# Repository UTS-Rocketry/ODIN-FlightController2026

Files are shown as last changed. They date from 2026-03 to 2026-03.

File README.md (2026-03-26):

# ODIN - UTS Rocketry – Flight Controller 2026

b32aecdc31f343ea89f31d750d7f50b3_T

## Version 1.0
Primary avionics flight controller for the 2026 AURC rocket.

This board manages flight state detection, sensor fusion, telemetry transmission, and onboard data logging using a 3.3V STM32-based embedded system.

---

## System Overview

### Microcontroller
- STM32 (F4 Series)
- 3.3V logic domain
- SWD debugging (ST-Link)
- Optional USB device (CDC / DFU)
- DMA-enabled peripherals
- Hardware timers for deterministic event timing

---

## Sensors

### Barometer (I2C)
- High-resolution pressure sensor
- Used for altitude estimation
- Data-ready interrupt supported (optional)
- VDD and VDDIO tied to 3.3V
- Local decoupling per datasheet

### IMU (Accelerometer + Gyroscope)
- Used for:
  - Boost detection
  - Apogee validation
  - Orientation monitoring
- Connected via SPI or I2C
- Interrupt-capable EXTI lines available

### GPS (UART)
- Real-time position tracking
- Logged to SD card
- Transmitted via LoRa telemetry
- Used for post-flight recovery

---

## Telemetry – SX1262 (SPI)

- LoRa-based long-range telemetry
- Configurable TX power & spreading factor
- SPI with DMA support
- Downlinked data:
  - Altitude
  - Velocity estimate
  - Flight state
  - GPS coordinates
  - Battery voltage

---

## Data Logging – microSD (SPI Mode)

- SPI selected over SDIO for routing simplicity and robustness
- 22Ω series resistor on SCK
- 10k pull-up on CS (DAT3)
- 0.1µF + 10µF local decoupling
- ESD protection on the connector

### Logged Parameters
- Timestamp
- Raw pressure
- Calculated altitude
- IMU acceleration & gyro
- GPS coordinates
- Flight state transitions
- Battery voltage
- Event flags

---

## Power Architecture

- Main system input rail
- 3.3V regulated logic rail
- ADC-based battery voltage monitoring (resistor divider)
- Local decoupling at each IC
- Bulk capacitance near SD and LoRa module

### Design Considerations
- All digital logic operates at 3.3V
- Short SPI traces with source termination
- Separation from switching regulator noise
- Solid ground reference plane

---

##  Programming & Debugging

### SWD (Primary Interface)
- SWDIO
- SWCLK
- GND
- 3.3V reference
- NRST (optional)

Used for:
- Firmware flashing
- Breakpoint debugging
- Register inspection

### USB (Optional)
- CDC virtual COM port for debug output
- Optional DFU firmware update support

---

### Core Features
- Sensor initialisation & health checks
- DMA-based peripheral handling
- Deterministic flight-state transitions
- SD logging with fault handling
- Telemetry packet scheduling
- Brownout and fault detection

---

# Contributors
 - Ollie Charleton: Avionics Lead
 - Michael Basangan: Software Lead
 - Aditya Sriram : Advisor

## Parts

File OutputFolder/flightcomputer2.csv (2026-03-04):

Reference | Qty | Value | LCSC
BZ1 | 1 | Buzzer | C96093
C1,C2,C5,C6,C7,C10,C11,C12,C14,C17,C18,C20,C21,C22,C23,C24,C25,C26,C27 | 19 | 100nf | C49678
C3,C4 | 2 | 2.2u | C19110
C8 | 1 | 4.7u | C1779
C9,C13,C28 | 3 | 1u | C28323
C15,C16 | 2 | 18p | C113825
C19 | 1 | 10u | C2932476
CAN_IN1,CAN_OUT1 | 2 | CAN | C17644051
D1 | 1 | NeoPixel_THT | C2827321
D2,D3 | 2 | D_Schottky | C113936
D4 | 1 | SRV05-4.TCT | C13612
D6 | 1 | 1N5819WS | C191023
FB1 | 1 | FerriteBead | C85840
J1 | 1 | Microsemi_FlashPro-JTAG-10 | C585350
J2,J4 | 2 | Pyro | C17644051
J5,J6 | 2 | Conn_01x05_Pin | C157991
J7 | 1 | Conn_Coaxial_Small | C3172376
J8 | 1 | Micro_SD_Card | C164170
J9 | 1 | USB_C_Receptacle_USB2.0_16P | C165948
PowerLED1 | 1 | RLED | C965799
Q1,Q2 | 2 | IRLML2502TRPBF | C2589
Q3 | 1 | BC817 | C39828
R1,R5,R10,R15,R17,R18,R20 | 7 | 10k | C84376
R2 | 1 | 100k | C96346
R3 | 1 | 1k | C95781
R4,R9 | 2 | 100R | C17408
R6,R11 | 2 | 75k | C17819
R7,R12 | 2 | 47k | C2933415
R8 | 1 | 120R | C269726
R13,R14 | 2 | 5.1k | C27834
R16 | 1 | 33R | C17557
R19 | 1 | 470r | C2907267
R21,R22 | 2 | 4.7k | C17673
SW1,SW2 | 2 | SAMZO G4R0015010 | C49393646
U1 | 1 | STM32F405RGT6 | C15742
U2 | 1 | SN65HVD230 | C1543812
U3 | 1 | PowerIn | C17644051
U4 | 1 | LDL1117-3.3 | C435835
U5 | 1 | RFM95W-915S2 | C2844473
U6 | 1 | MPL3115A2R1 | C54429
U7 | 1 | LSM6DS3TR-C | C967633
U8 | 1 | W25Q128JVP | C190862
U9 | 1 | H3LIS331DL | C2655074
Y1 | 1 | 8mhz | C19723344

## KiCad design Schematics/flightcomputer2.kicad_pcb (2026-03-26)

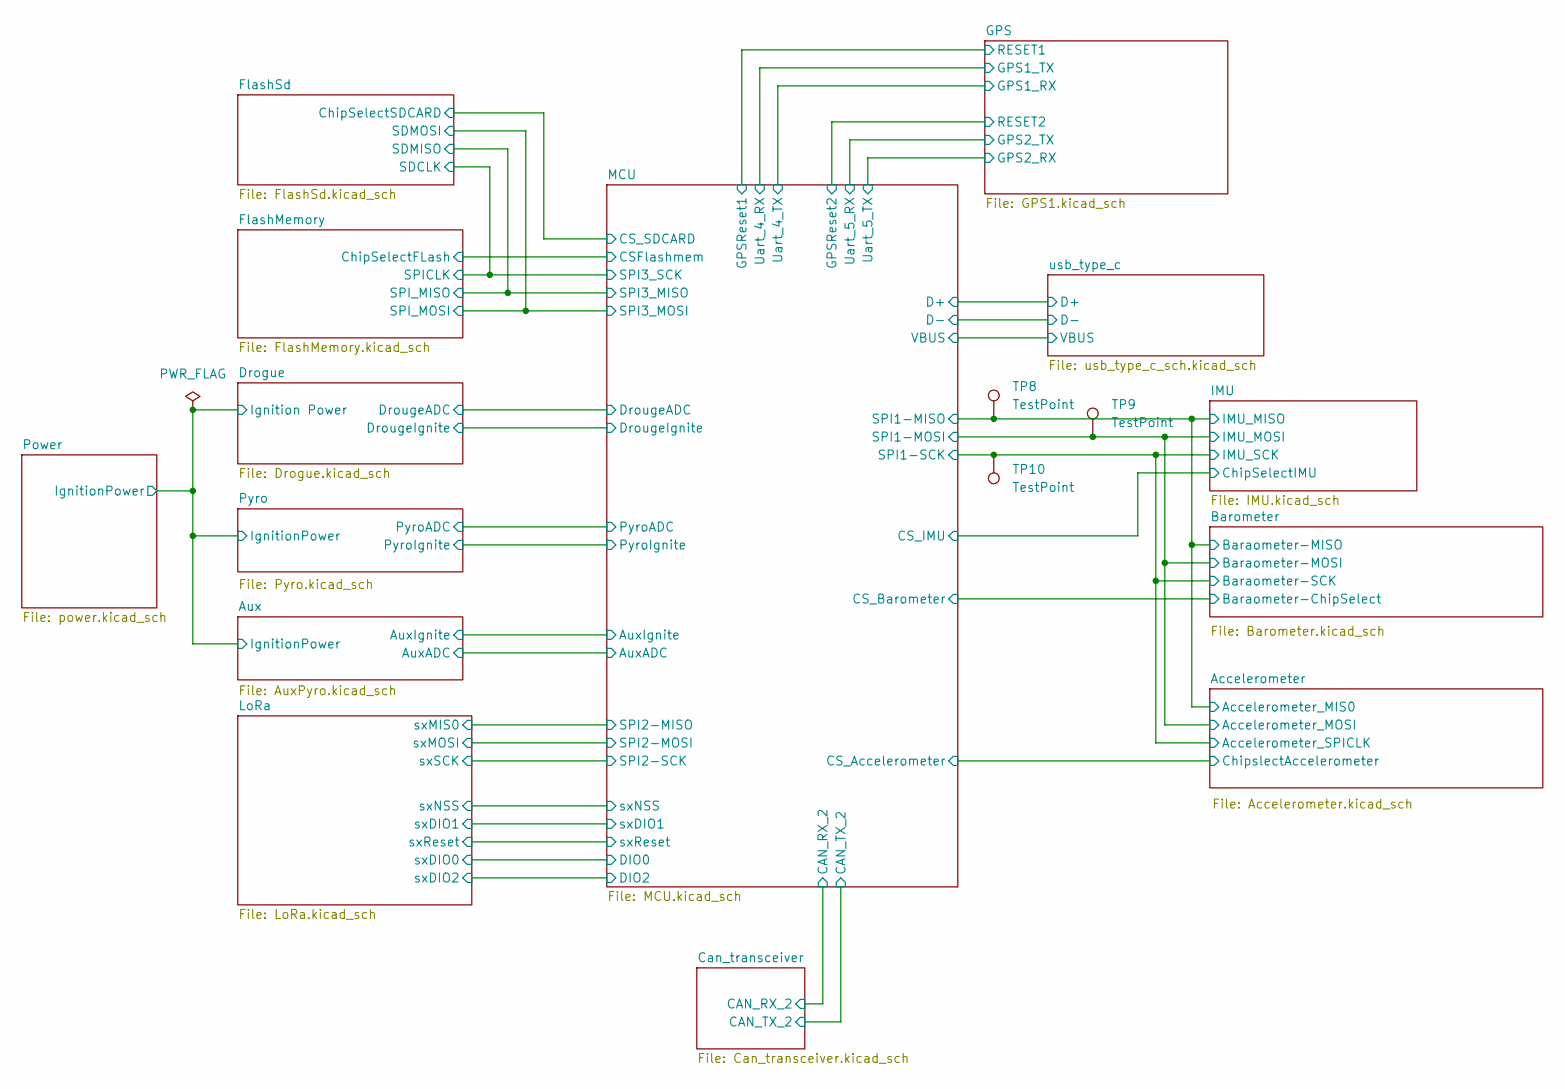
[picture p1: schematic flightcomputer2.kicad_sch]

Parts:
TP8, TP9, TP10: TestPoint; TestPoint_Pad_1.5x1.5mm

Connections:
/Accelerometer/Accelerometer_MIS0: TP8.1 (1_1); also elsewhere on the board
/Accelerometer/Accelerometer_MOSI: TP9.1 (1_1); also elsewhere on the board
/Accelerometer/Accelerometer_SPICLK: TP10.1 (1_1); also elsewhere on the board

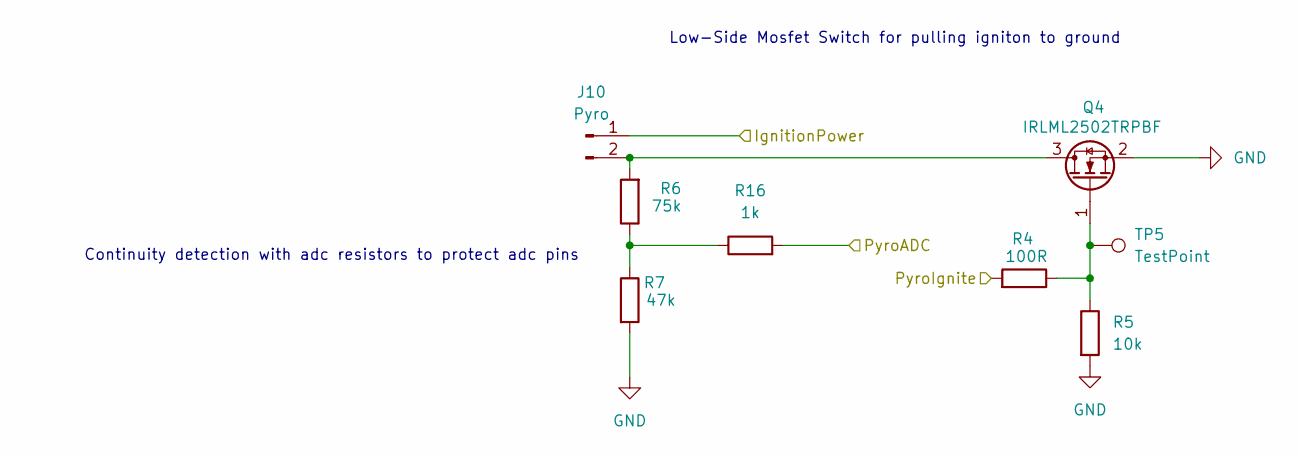
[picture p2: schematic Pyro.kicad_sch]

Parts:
J10: Pyro; MOLEX_26013114; LCSC C17644051
Q4: IRLML2502TRPBF; SOT23; LCSC C2589
R4: 100R; R_0805_2012Metric_Pad1.20x1.40mm_HandSolder; LCSC C17408
R5: 10k; R_0805_2012Metric_Pad1.20x1.40mm_HandSolder; LCSC C17414
R6: 75k; R_0805_2012Metric_Pad1.20x1.40mm_HandSolder; LCSC C17819
R7: 47k; R_0805_2012Metric_Pad1.20x1.40mm_HandSolder; LCSC C17713
R16: 1k; R_0805_2012Metric_Pad1.20x1.40mm_HandSolder; LCSC C17513
TP5: TestPoint; TestPoint_Pad_1.5x1.5mm

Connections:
/Aux/IgnitionPower: J10.1; also elsewhere on the board
/MCU/PyroADC: R16.2; also elsewhere on the board
/MCU/PyroIgnite: R4.2; also elsewhere on the board
GND: Q4.2 (S), R5.2, R7.2; also elsewhere on the board
unnamed: J10.2, Q4.3 (D), R6.2
unnamed: Q4.1 (G), R4.1, R5.1, TP5.1 (1_1)
unnamed: R6.1, R7.1, R16.1

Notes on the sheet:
Low-Side Mosfet Switch for pulling igniton to ground
Continuity detection with adc resistors to protect adc pins

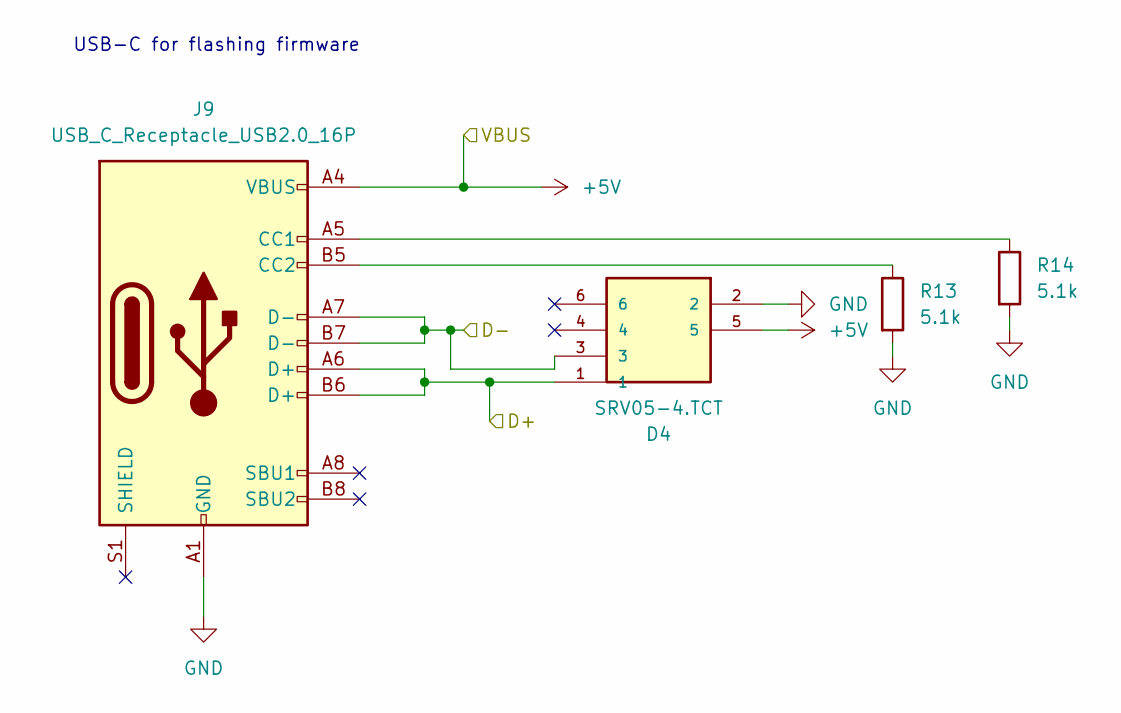
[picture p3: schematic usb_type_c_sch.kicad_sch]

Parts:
D4: SRV05-4.TCT; SOT95P280X145-6N; MANUFACTURER_PART_NUMBER SRV05-4.TCT; LCSC C13612
J9: USB_C_Receptacle_USB2.0_16P; USB_C_Receptacle_HRO_TYPE-C-31-M-12; LCSC C165948
R13, R14: 5.1k; R_0805_2012Metric_Pad1.20x1.40mm_HandSolder; LCSC C27834

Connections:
+5V: D4.5, J9.A4 (VBUS), J9.A9 (VBUS), J9.B4 (VBUS), J9.B9 (VBUS); also elsewhere on the board
/MCU/D+: D4.1, J9.A6 (D+), J9.B6 (D+); also elsewhere on the board
/MCU/D-: D4.3, J9.A7 (D-), J9.B7 (D-); also elsewhere on the board
GND: D4.2, J9.A1 (GND), J9.A12 (GND), J9.B1 (GND), J9.B12 (GND), R13.2, R14.2; also elsewhere on the board
unnamed: J9.A5 (CC1), R14.1
unnamed: J9.B5 (CC2), R13.1

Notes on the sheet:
USB-C for flashing firmware

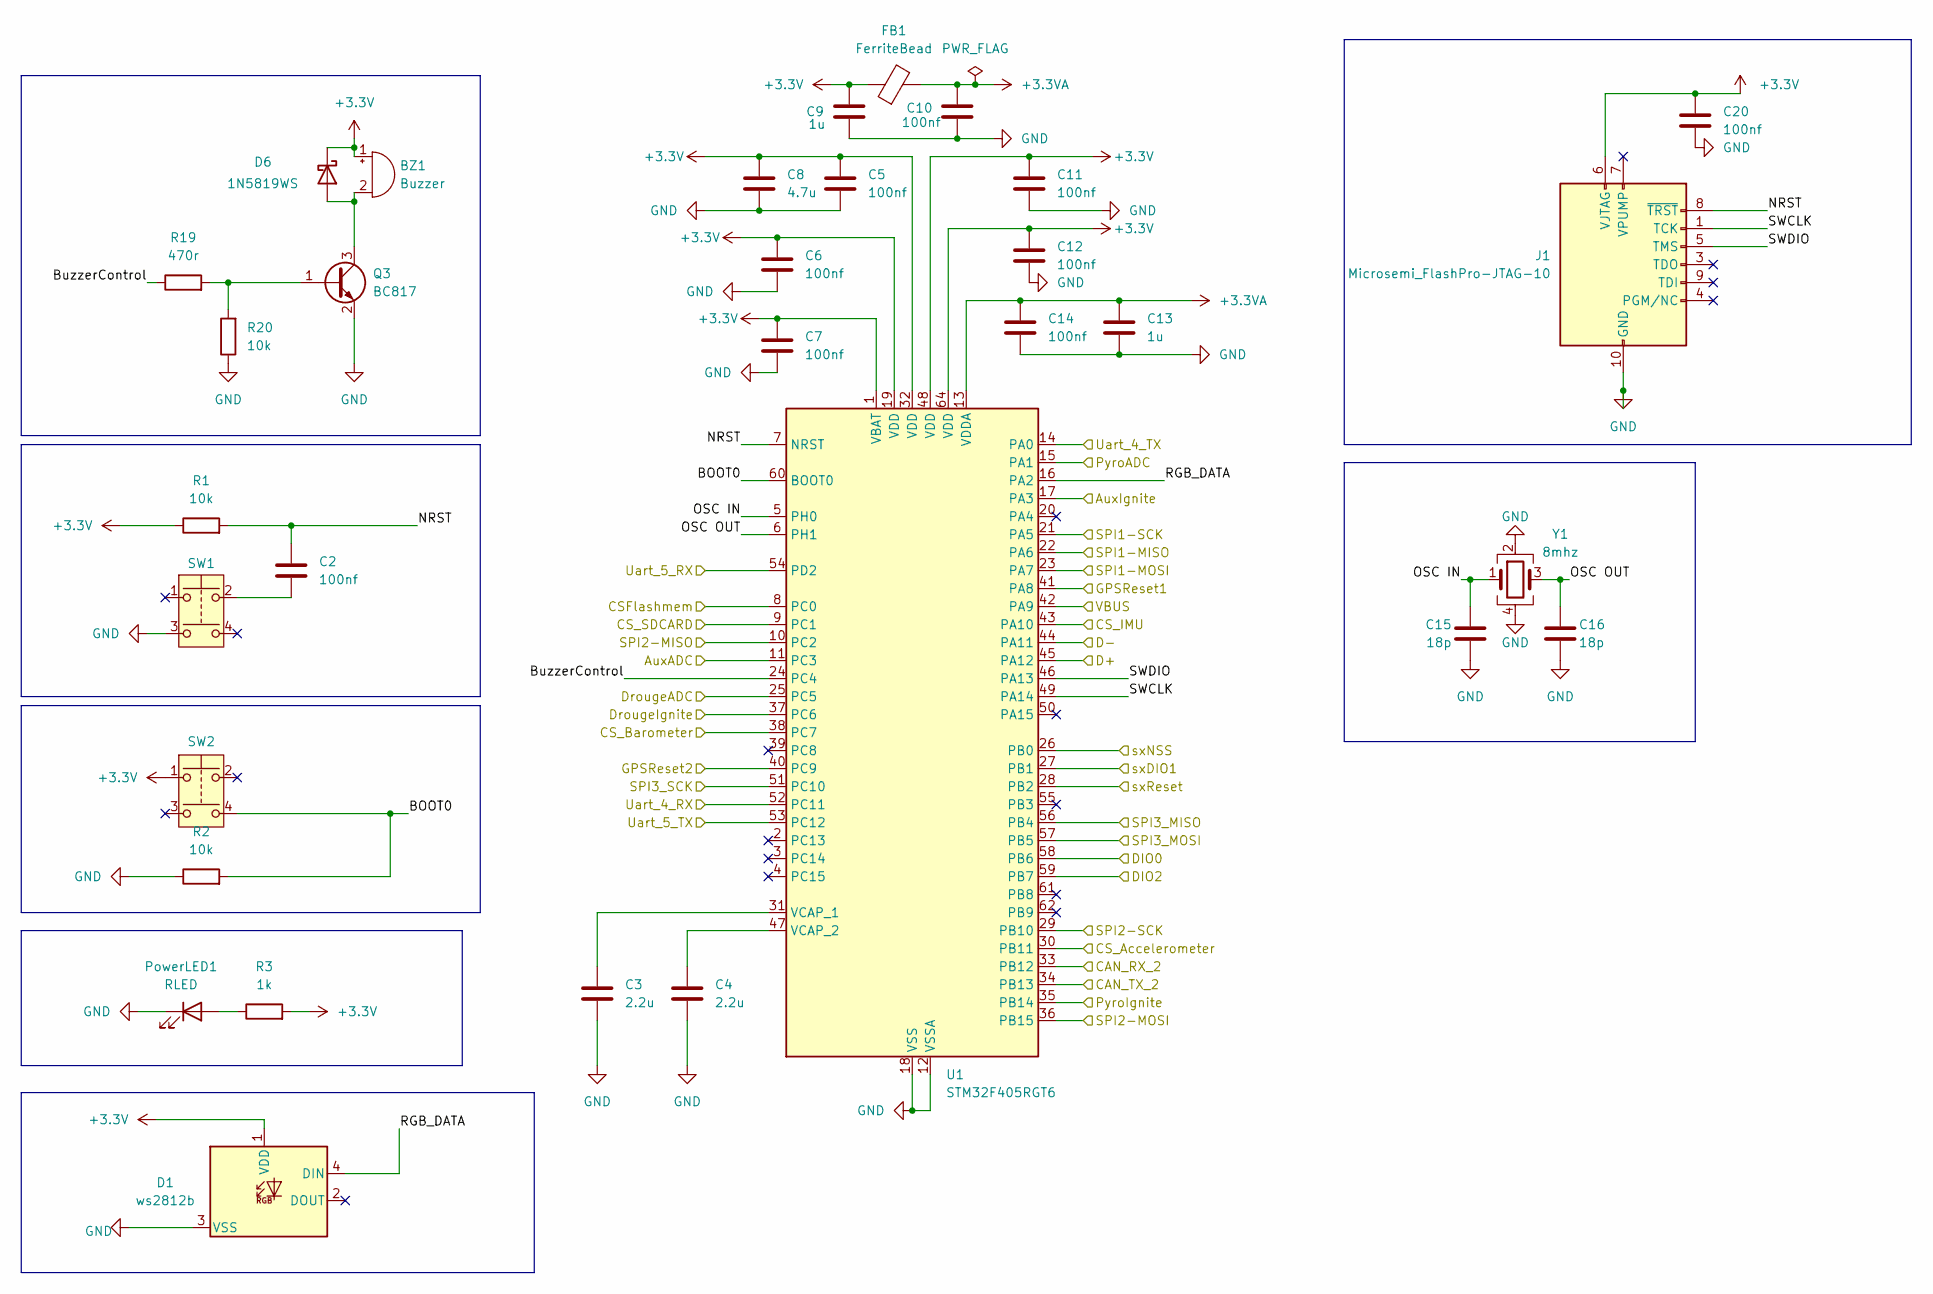
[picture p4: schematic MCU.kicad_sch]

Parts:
BZ1: Buzzer; Buzzer_12x9.5RM7.6; LCSC C96093
C2, C5, C6, C7, C10, C11, C12, C14, C20: 100nf; C_0805_2012Metric_Pad1.18x1.45mm_HandSolder; LCSC C49678
C3, C4: 2.2u; C_0805_2012Metric_Pad1.18x1.45mm_HandSolder; LCSC C377773
C8: 4.7u; C_0805_2012Metric_Pad1.18x1.45mm_HandSolder; LCSC C1779
C9, C13: 1u; C_0805_2012Metric_Pad1.18x1.45mm_HandSolder; LCSC C28323
C15, C16: 18p; C_0805_2012Metric_Pad1.18x1.45mm_HandSolder; LCSC C113825
D1: ws2812b; LED_WS2812B_PLCC4_5.0x5.0mm_P3.2mm; LCSC C2761795
D6: 1N5819WS; D_SOD-323; LCSC C191023
FB1: FerriteBead; R_0805_2012Metric_Pad1.20x1.40mm_HandSolder; LCSC C1015
J1: Microsemi_FlashPro-JTAG-10; PinHeader_2x05_P1.27mm_Vertical; LCSC C22438120
PowerLED1: RLED; LED_0603_1608Metric_Pad1.05x0.95mm_HandSolder; LCSC C965799
Q3: BC817; SOT-23; LCSC C39828
R1, R20: 10k; R_0805_2012Metric_Pad1.20x1.40mm_HandSolder; LCSC C17414
R2: 10k; R_0805_2012Metric_Pad1.20x1.40mm_HandSolder; LCSC C149504
R3: 1k; R_0805_2012Metric_Pad1.20x1.40mm_HandSolder; LCSC C17513
R19: 470r; R_0805_2012Metric_Pad1.20x1.40mm_HandSolder; LCSC C17710
SW1, SW2: SAMZO G4R0015010; LCSC C49393646
U1: STM32F405RGT6; LQFP-64_10x10mm_P0.5mm; LCSC C15742
Y1: 8mhz; Crystal_SMD_3225-4Pin_3.2x2.5mm_HandSoldering; LCSC C19723344

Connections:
+3.3V: BZ1.1 (+), C5.1, C6.1, C7.1, C8.1, C9.2, C11.1, C12.1, C20.1, D1.1 (VDD), D6.1 (K), FB1.1, J1.6 (VJTAG), R1.1, R3.2, SW2.1, U1.1 (VBAT), U1.19 (VDD), U1.32 (VDD), U1.48 (VDD), U1.64 (VDD); also elsewhere on the board
+3.3VA: C10.2, C13.1, C14.1, FB1.2, U1.13 (VDDA)
+5V: U1.42 (PA9); also elsewhere on the board
/Accelerometer/Accelerometer_MIS0: U1.22 (PA6); also elsewhere on the board
/Accelerometer/Accelerometer_MOSI: U1.23 (PA7); also elsewhere on the board
/Accelerometer/Accelerometer_SPICLK: U1.21 (PA5); also elsewhere on the board
/Accelerometer/ChipslectAccelerometer: U1.30 (PB11); also elsewhere on the board
/Aux/AuxADC: U1.11 (PC3); also elsewhere on the board
/Aux/AuxIgnite: U1.17 (PA3); also elsewhere on the board
/Barometer/Baraometer-ChipSelect: U1.38 (PC7); also elsewhere on the board
/Can_transceiver/CAN_RX_2: U1.33 (PB12); also elsewhere on the board
/Can_transceiver/CAN_TX_2: U1.34 (PB13); also elsewhere on the board
/Drogue/DrougeADC: U1.25 (PC5); also elsewhere on the board
/Drogue/DrougeIgnite: U1.37 (PC6); also elsewhere on the board
/FlashMemory/ChipSelectFLash: U1.8 (PC0); also elsewhere on the board
/FlashMemory/SPICLK: U1.51 (PC10); also elsewhere on the board
/FlashMemory/SPI_MISO: U1.56 (PB4); also elsewhere on the board
/FlashMemory/SPI_MOSI: U1.57 (PB5); also elsewhere on the board
/FlashSd/ChipSelectSDCARD: U1.9 (PC1); also elsewhere on the board
/GPS/GPS1_RX: U1.14 (PA0); also elsewhere on the board
/GPS/GPS1_TX: U1.52 (PC11); also elsewhere on the board
/GPS/GPS2_RX: U1.53 (PC12); also elsewhere on the board
/GPS/GPS2_TX: U1.54 (PD2); also elsewhere on the board
/GPS/RESET1: U1.41 (PA8); also elsewhere on the board
/GPS/RESET2: U1.40 (PC9); also elsewhere on the board
/IMU/ChipSelectIMU: U1.43 (PA10); also elsewhere on the board
/LoRa/sxDIO0: U1.58 (PB6); also elsewhere on the board
/LoRa/sxDIO1: U1.27 (PB1); also elsewhere on the board
/LoRa/sxDIO2: U1.59 (PB7); also elsewhere on the board
/LoRa/sxMIS0: U1.10 (PC2); also elsewhere on the board
/LoRa/sxMOSI: U1.36 (PB15); also elsewhere on the board
/LoRa/sxNSS: U1.26 (PB0); also elsewhere on the board
/LoRa/sxReset: U1.28 (PB2); also elsewhere on the board
/LoRa/sxSCK: U1.29 (PB10); also elsewhere on the board
/MCU/BOOT0: R2.2, SW2.4, U1.60 (BOOT0)
/MCU/BuzzerControl: R19.1, U1.24 (PC4)
/MCU/D+: U1.45 (PA12); also elsewhere on the board
/MCU/D-: U1.44 (PA11); also elsewhere on the board
/MCU/NRST: C2.1, J1.8 (~TRST), R1.2, U1.7 (NRST)
/MCU/OSC IN: C15.1, U1.5 (PH0), Y1.1
/MCU/OSC OUT: C16.1, U1.6 (PH1), Y1.3
/MCU/PyroADC: U1.15 (PA1); also elsewhere on the board
/MCU/PyroIgnite: U1.35 (PB14); also elsewhere on the board
/MCU/RGB_DATA: D1.4 (DIN), U1.16 (PA2)
/MCU/SWCLK: J1.1 (TCK), U1.49 (PA14)
/MCU/SWDIO: J1.5 (TMS), U1.46 (PA13)
GND: C3.2, C4.2, C5.2, C6.2, C7.2, C8.2, C9.1, C10.1, C11.2, C12.2, C13.2, C14.2, C15.2, C16.2, C20.2, D1.3 (VSS), J1.2 (GND), J1.10 (GND), PowerLED1.1 (K), Q3.2 (E), R2.1, R20.1, SW1.3, U1.12 (VSSA), U1.18 (VSS), U1.63 (VSS), Y1.2, Y1.4; also elsewhere on the board
unnamed: BZ1.2 (-), D6.2 (A), Q3.3 (C)
unnamed: C2.2, SW1.2
unnamed: PowerLED1.2 (A), R3.1
unnamed: Q3.1 (B), R19.2, R20.2
unnamed: C3.1, U1.31 (VCAP_1)
unnamed: C4.1, U1.47 (VCAP_2)

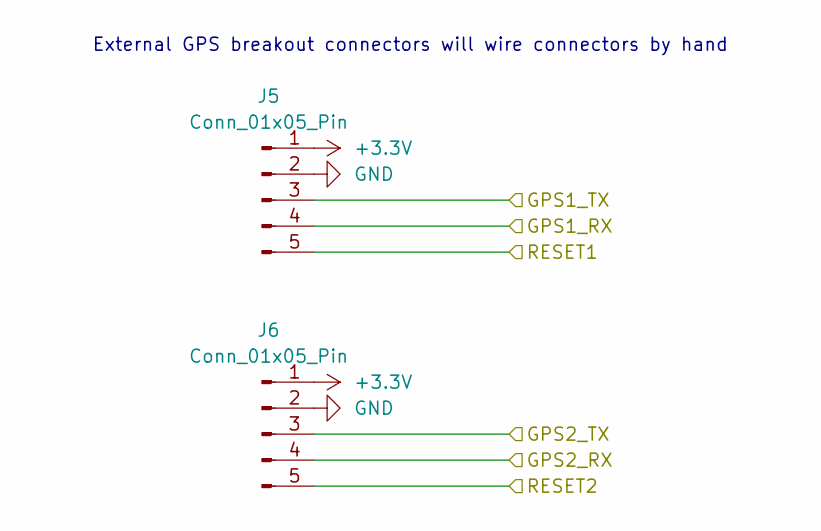
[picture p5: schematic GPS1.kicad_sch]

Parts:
J5, J6: Conn_01x05_Pin; JST_B5B-XH-A; LCSC C157991

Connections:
+3.3V: J5.1, J6.1; also elsewhere on the board
/GPS/GPS1_RX: J5.4; also elsewhere on the board
/GPS/GPS1_TX: J5.3; also elsewhere on the board
/GPS/GPS2_RX: J6.4; also elsewhere on the board
/GPS/GPS2_TX: J6.3; also elsewhere on the board
/GPS/RESET1: J5.5; also elsewhere on the board
/GPS/RESET2: J6.5; also elsewhere on the board
GND: J5.2, J6.2; also elsewhere on the board

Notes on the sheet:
External GPS breakout connectors will wire connectors by hand

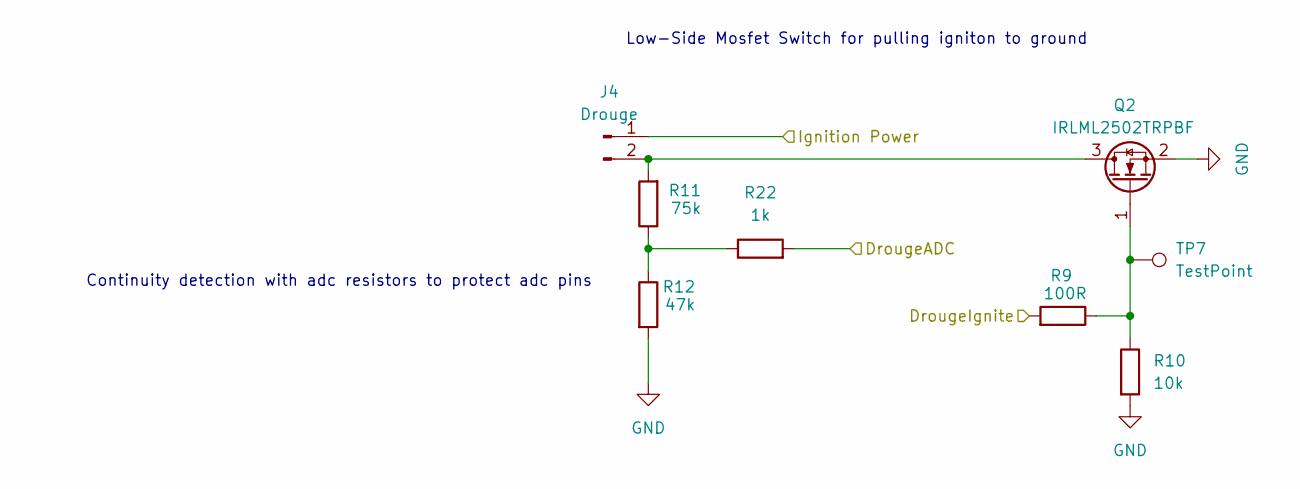
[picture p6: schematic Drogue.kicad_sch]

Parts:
J4: Drouge; MOLEX_26013114; LCSC C17644051
Q2: IRLML2502TRPBF; SOT23; LCSC C2589
R9: 100R; R_0805_2012Metric_Pad1.20x1.40mm_HandSolder; LCSC C17408
R10: 10k; R_0805_2012Metric_Pad1.20x1.40mm_HandSolder; LCSC C17414
R11: 75k; R_0805_2012Metric_Pad1.20x1.40mm_HandSolder; LCSC C17819
R12: 47k; R_0805_2012Metric_Pad1.20x1.40mm_HandSolder; LCSC C17713
R22: 1k; R_0805_2012Metric_Pad1.20x1.40mm_HandSolder; LCSC C17513
TP7: TestPoint; TestPoint_Pad_1.5x1.5mm

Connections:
/Aux/IgnitionPower: J4.1; also elsewhere on the board
/Drogue/DrougeADC: R22.2; also elsewhere on the board
/Drogue/DrougeIgnite: R9.2; also elsewhere on the board
GND: Q2.2 (S), R10.2, R12.2; also elsewhere on the board
unnamed: J4.2, Q2.3 (D), R11.2
unnamed: Q2.1 (G), R9.1, R10.1, TP7.1 (1_1)
unnamed: R11.1, R12.1, R22.1

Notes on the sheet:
Continuity detection with adc resistors to protect adc pins
Low-Side Mosfet Switch for pulling igniton to ground

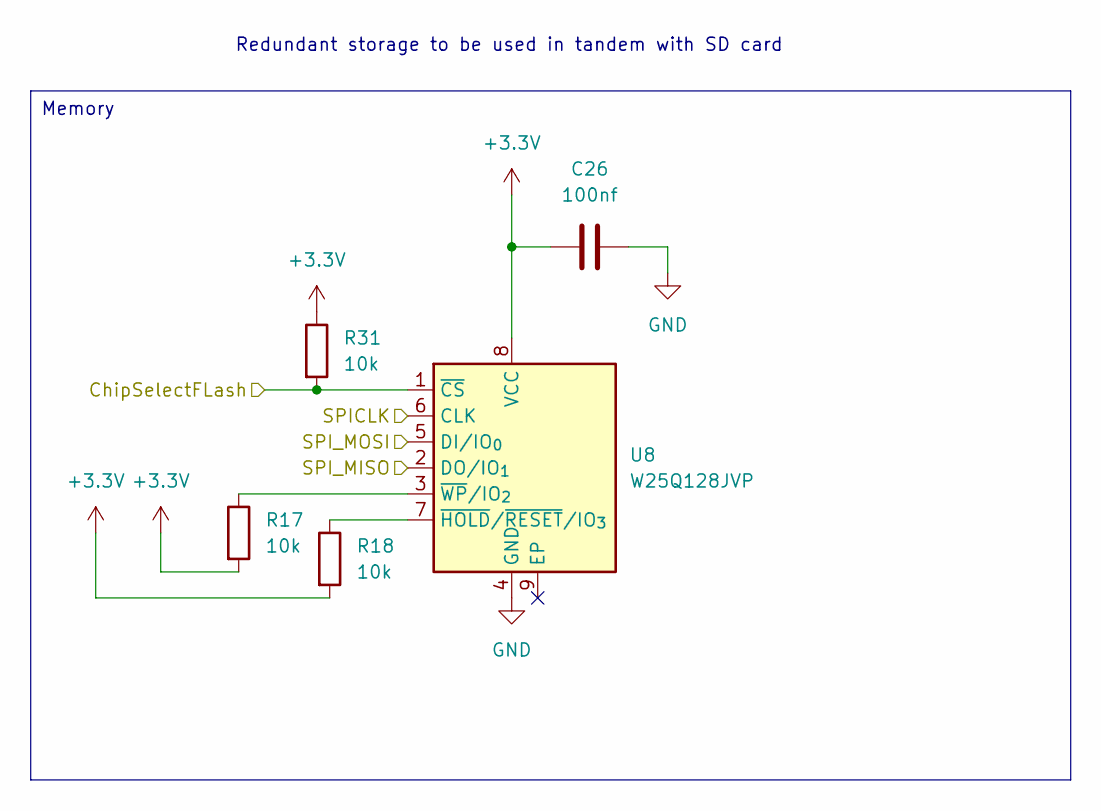
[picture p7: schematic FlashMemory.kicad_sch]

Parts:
C26: 100nf; C_0805_2012Metric_Pad1.18x1.45mm_HandSolder; LCSC C49678
R17, R18, R31: 10k; R_0805_2012Metric_Pad1.20x1.40mm_HandSolder; LCSC C17414
U8: W25Q128JVP; WSON-8-1EP_6x5mm_P1.27mm_EP3.4x4.3mm; LCSC C190862

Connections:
+3.3V: C26.1, R17.2, R18.2, R31.1, U8.8 (VCC); also elsewhere on the board
/FlashMemory/ChipSelectFLash: R31.2, U8.1 (~CS); also elsewhere on the board
/FlashMemory/SPICLK: U8.6 (CLK); also elsewhere on the board
/FlashMemory/SPI_MISO: U8.2 (DO/IO_{1}); also elsewhere on the board
/FlashMemory/SPI_MOSI: U8.5 (DI/IO_{0}); also elsewhere on the board
GND: C26.2, U8.4 (GND); also elsewhere on the board
unnamed: R18.1, U8.7 (~HOLD/~RESET/IO_{3})
unnamed: R17.1, U8.3 (~WP/IO_{2})

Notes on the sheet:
Redundant storage to be used in tandem with SD card
Memory

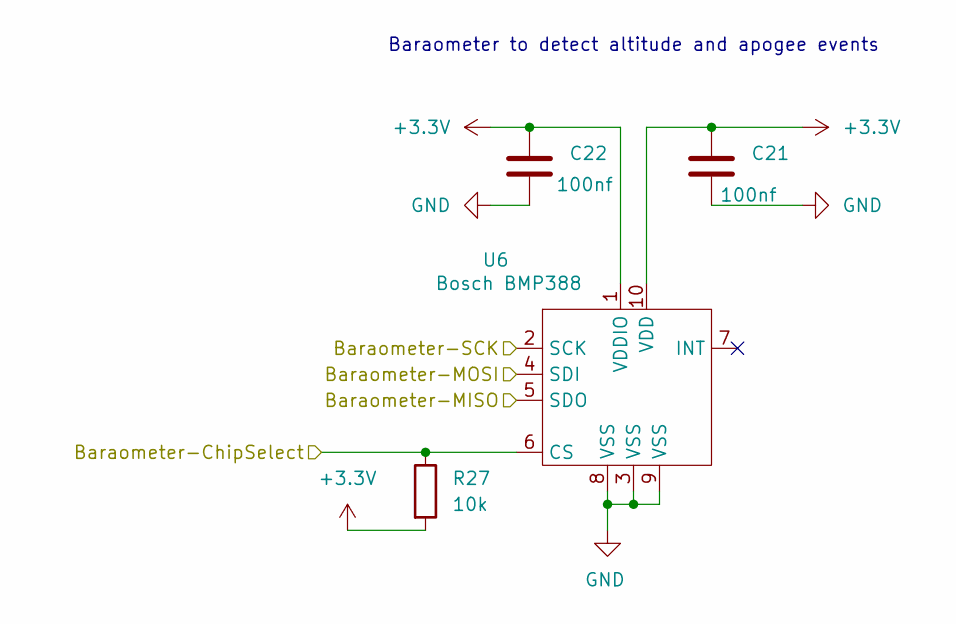
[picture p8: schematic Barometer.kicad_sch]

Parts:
C21, C22: 100nf; C_0805_2012Metric_Pad1.18x1.45mm_HandSolder; LCSC C49678
R27: 10k; R_0805_2012Metric_Pad1.20x1.40mm_HandSolder; LCSC C17414
U6: Bosch BMP388; PQFN50P200X200X80-10N; LCSC C779278

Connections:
+3.3V: C21.1, C22.1, R27.2, U6.1 (VDDIO), U6.10 (VDD); also elsewhere on the board
/Accelerometer/Accelerometer_MIS0: U6.5 (SDO); also elsewhere on the board
/Accelerometer/Accelerometer_MOSI: U6.4 (SDI); also elsewhere on the board
/Accelerometer/Accelerometer_SPICLK: U6.2 (SCK); also elsewhere on the board
/Barometer/Baraometer-ChipSelect: R27.1, U6.6 (CS); also elsewhere on the board
GND: C21.2, C22.2, U6.3 (VSS), U6.8 (VSS), U6.9 (VSS); also elsewhere on the board

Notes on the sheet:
Baraometer to detect altitude and apogee events

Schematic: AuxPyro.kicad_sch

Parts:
J2: Pyro; MOLEX_26013114; LCSC C17644051
Q1: IRLML2502TRPBF; SOT23; LCSC C2589
R21: 1k; R_0805_2012Metric_Pad1.20x1.40mm_HandSolder; LCSC C17513
R23: 100R; R_0805_2012Metric_Pad1.20x1.40mm_HandSolder; LCSC C17408
R24: 10k; R_0805_2012Metric_Pad1.20x1.40mm_HandSolder; LCSC C17414
R25: 75k; R_0805_2012Metric_Pad1.20x1.40mm_HandSolder; LCSC C17819
R26: 47k; R_0805_2012Metric_Pad1.20x1.40mm_HandSolder; LCSC C17713
TP6: TestPoint; TestPoint_Pad_1.5x1.5mm

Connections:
/Aux/AuxADC: R21.2; also elsewhere on the board
/Aux/AuxIgnite: R23.2; also elsewhere on the board
/Aux/IgnitionPower: J2.1; also elsewhere on the board
GND: Q1.2 (S), R24.2, R26.2; also elsewhere on the board
unnamed: J2.2, Q1.3 (D), R25.2
unnamed: Q1.1 (G), R23.1, R24.1, TP6.1 (1_1)
unnamed: R21.1, R25.1, R26.1

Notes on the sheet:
Continuity detection with adc resistors to protect adc pins
Low-Side Mosfet Switch for pulling igniton to ground

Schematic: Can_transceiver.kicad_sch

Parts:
C17: 100nf; C_0805_2012Metric_Pad1.18x1.45mm_HandSolder; LCSC C49678
CAN_IN1: CAN; MOLEX_26013114; LCSC C17644051
CAN_OUT1: CAN; MOLEX_26013114; LCSC C17644051
JP1: SolderJumper_2_Open; SolderJumper-2_P1.3mm_Open_TrianglePad1.0x1.5mm; not fitted
R8: 120R; R_0805_2012Metric_Pad1.20x1.40mm_HandSolder; LCSC C17437
U2: SN65HVD230; SOIC-8_3.9x4.9mm_P1.27mm; LCSC C12084

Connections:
+3.3V: C17.1, U2.3 (VCC); also elsewhere on the board
/Can_transceiver/CANH: CAN_IN1.1, CAN_OUT1.1, R8.1, U2.7 (CANH)
/Can_transceiver/CANL: CAN_IN1.2, CAN_OUT1.2, JP1.2 (B), U2.6 (CANL)
/Can_transceiver/CAN_RX_2: U2.4 (R); also elsewhere on the board
/Can_transceiver/CAN_TX_2: U2.1 (D); also elsewhere on the board
GND: C17.2, U2.2 (GND), U2.8 (Rs); also elsewhere on the board
unnamed: JP1.1 (A), R8.2

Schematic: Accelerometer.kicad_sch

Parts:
C27: 100nf; C_0805_2012Metric_Pad1.18x1.45mm_HandSolder; LCSC C49678
C28: 1u; C_0805_2012Metric_Pad1.18x1.45mm_HandSolder; LCSC C28323
R32: 10k; R_0805_2012Metric_Pad1.20x1.40mm_HandSolder; LCSC C17414
U9: H3LIS331DL; PQFN50P300X300X100-16N; LCSC C2655074

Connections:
+3.3V: C27.2, C28.2, R32.1, U9.1 (Vdd_IO), U9.14 (VDD), U9.15 (VDD); also elsewhere on the board
/Accelerometer/Accelerometer_MIS0: U9.7 (SDO/SA0); also elsewhere on the board
/Accelerometer/Accelerometer_MOSI: U9.6 (SDA/SDI/SDO); also elsewhere on the board
/Accelerometer/Accelerometer_SPICLK: U9.4 (SCL/SPC); also elsewhere on the board
/Accelerometer/ChipslectAccelerometer: R32.2, U9.8 (CS); also elsewhere on the board
GND: C27.1, C28.1, U9.5 (GND), U9.12 (GND); also elsewhere on the board

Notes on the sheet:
High g imu for liftoff data

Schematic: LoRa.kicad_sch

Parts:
C1: 100nf; C_0805_2012Metric_Pad1.18x1.45mm_HandSolder; LCSC C49678
J7: Conn_Coaxial_Small; SMA_Amphenol_132291_Vertical; LCSC C3172376
U5: RFM95W-915S2; XCVR_RFM95W-915S2; LCSC C2844473

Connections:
+3.3V: C1.1, U5.13 (3.3V); also elsewhere on the board
/LoRa/sxDIO0: U5.14 (DIO0); also elsewhere on the board
/LoRa/sxDIO1: U5.15 (DIO1); also elsewhere on the board
/LoRa/sxDIO2: U5.16 (DIO2); also elsewhere on the board
/LoRa/sxMIS0: U5.2 (MISO); also elsewhere on the board
/LoRa/sxMOSI: U5.3 (MOSI); also elsewhere on the board
/LoRa/sxNSS: U5.5 (NSS); also elsewhere on the board
/LoRa/sxReset: U5.6 (RESET); also elsewhere on the board
/LoRa/sxSCK: U5.4 (SCK); also elsewhere on the board
GND: C1.2, J7.2 (Ext), U5.1 (GND), U5.8 (GND), U5.10 (GND); also elsewhere on the board
unnamed: J7.1 (In), U5.9 (ANT)

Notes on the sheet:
Lora module to coaxial connector

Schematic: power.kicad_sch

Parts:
C18: 100nf; C_0805_2012Metric_Pad1.18x1.45mm_HandSolder; LCSC C49678
C19: 10u; C_0805_2012Metric_Pad1.18x1.45mm_HandSolder; LCSC C15850
D2, D3: D_Schottky; D_2114_3652Metric; LCSC C113936
Q6: Q_PMOS_GSD; SOIC127P599X175-8N; LCSC C16072
R30: 47k; R_0805_2012Metric_Pad1.20x1.40mm_HandSolder; LCSC C17713
TP1, TP2, TP3: TestPoint; TestPoint_Pad_1.5x1.5mm
TP4: TestPoint; TestPoint_Pad_2.5x2.5mm
U3: PowerIn; MOLEX_26013114; LCSC C17644051
U4: LDL1117-3.3; SOT230P700X180-4N; LCSC C435835

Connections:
+3.3V: C19.1, TP3.1 (1_1), U4.3 (Vout), U4.4 (Vout); also elsewhere on the board
+5V: D3.2 (A); also elsewhere on the board
+BATT: Q6.1 (S), Q6.2 (Source), Q6.3 (Source), TP1.1 (1_1), U3.1
/Aux/IgnitionPower: D2.2 (A), Q6.5 (D), Q6.6 (Drain), Q6.7 (Drain), TP2.1 (1_1); also elsewhere on the board
GND: C18.2, C19.2, R30.2, TP4.1 (1_1), U3.2, U4.2 (GND); also elsewhere on the board
unnamed: C18.1, D2.1 (K), D3.1 (K), U4.1 (Vin)
unnamed: Q6.4 (G), R30.1

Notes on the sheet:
Flowback protection for usb and battery
The main protection point for the mosfet is the adc continuty checking pins
P-mosfet for reverse polarity protection (be advised extra pins are there just to sync with the footprint but treated as a normal p-mosfet)
Power in connector

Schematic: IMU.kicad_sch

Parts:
C24, C25: 100nf; C_0805_2012Metric_Pad1.18x1.45mm_HandSolder; LCSC C49678
R36: 10k; R_0805_2012Metric_Pad1.20x1.40mm_HandSolder; LCSC C17414
U7: LSM6DS3TR-C; LGA-14-2.5X3MM; LCSC C2655100

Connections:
+3.3V: C24.1, C25.1, R36.1, U7.2 (SDx), U7.3 (SCx), U7.5 (VDDIO), U7.8 (VDD); also elsewhere on the board
/Accelerometer/Accelerometer_MIS0: U7.1 (SDO/SA0); also elsewhere on the board
/Accelerometer/Accelerometer_MOSI: U7.14 (SDA); also elsewhere on the board
/Accelerometer/Accelerometer_SPICLK: U7.13 (SCL); also elsewhere on the board
/IMU/ChipSelectIMU: R36.2, U7.12 (CS); also elsewhere on the board
GND: C24.2, C25.2, U7.6 (GND), U7.7 (GND); also elsewhere on the board

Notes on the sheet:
Imu for control systems and data logging

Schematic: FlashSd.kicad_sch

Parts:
J8: Micro_SD_Card; microSD_HC_Molex_47219-2001; LCSC C164170
R15: 10k; R_0805_2012Metric_Pad1.20x1.40mm_HandSolder; LCSC C17414

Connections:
+3.3V: J8.4 (VDD), R15.1; also elsewhere on the board
/FlashMemory/SPICLK: J8.5 (CLK); also elsewhere on the board
/FlashMemory/SPI_MISO: J8.3 (CMD); also elsewhere on the board
/FlashMemory/SPI_MOSI: J8.7 (DAT0); also elsewhere on the board
/FlashSd/ChipSelectSDCARD: J8.2 (DAT3/CD), R15.2; also elsewhere on the board
GND: J8.6 (VSS), J8.9 (SHIELD); also elsewhere on the board

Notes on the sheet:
SD Card for flight telemetry logging and possible lookup tables for control systems

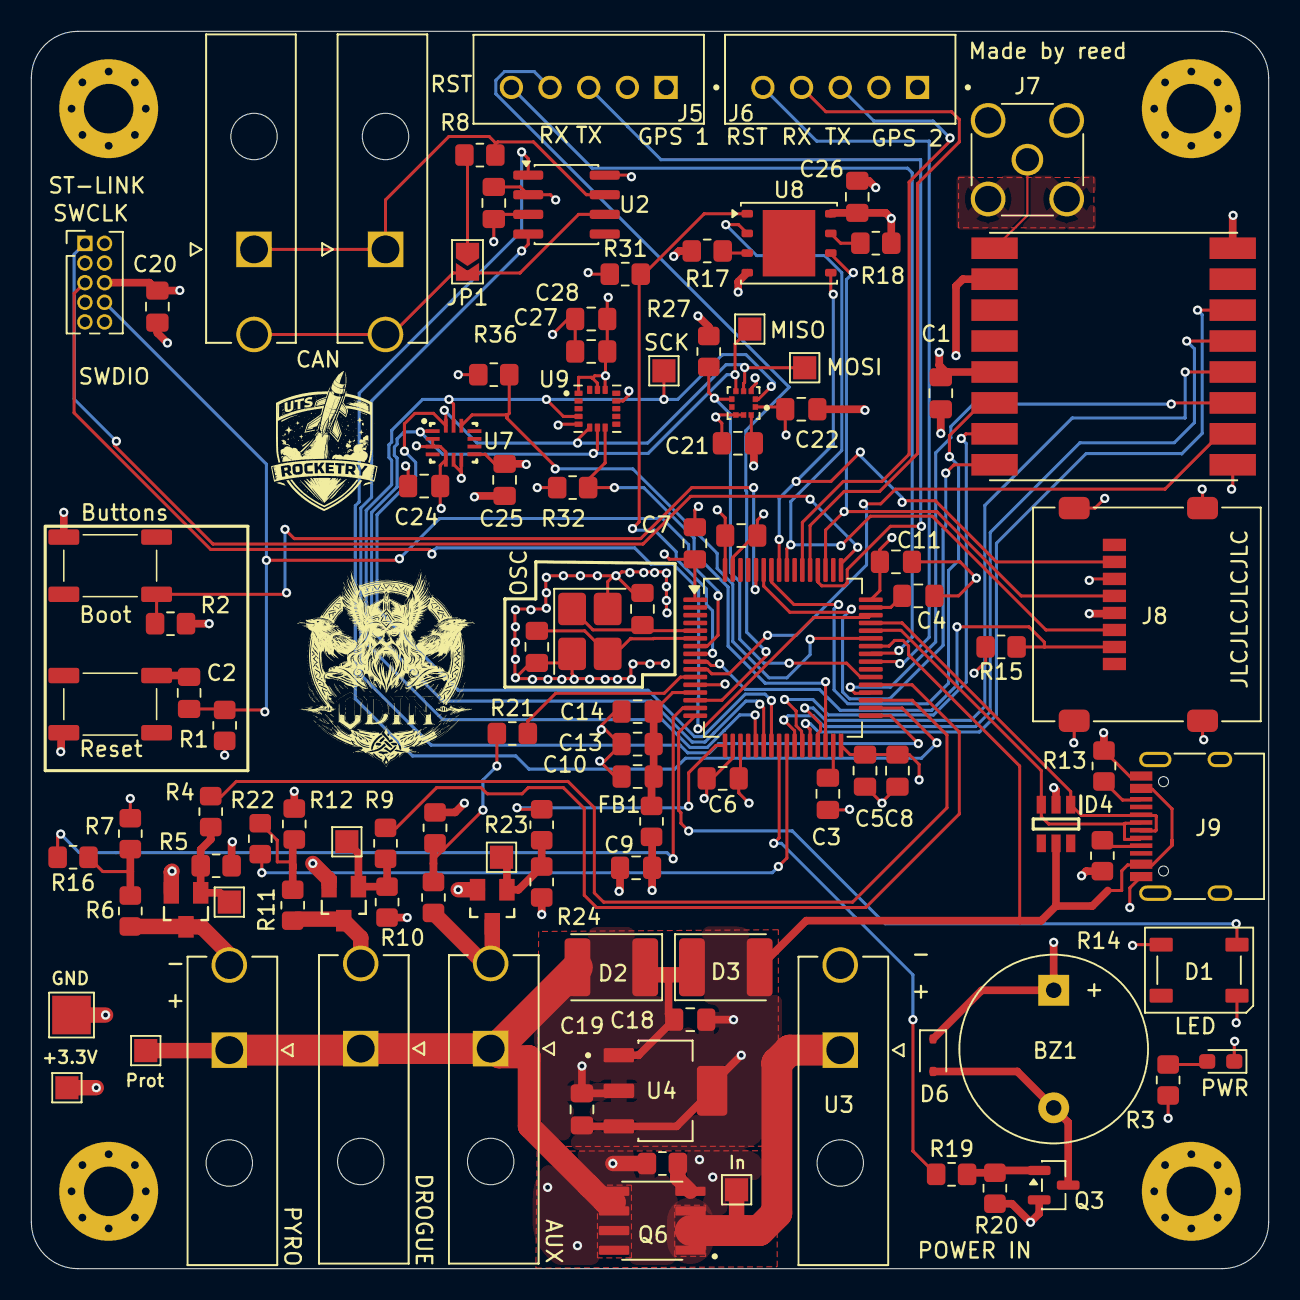
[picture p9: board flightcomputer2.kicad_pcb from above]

Board: 4 copper layers, 80.0 x 80.0 mm, 105 parts (0 on the bottom side), 74 nets.

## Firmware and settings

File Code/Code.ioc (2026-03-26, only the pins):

Mcu.UserName=STM32F405RGTx
PA0-WKUP.Signal=UART4_TX
PA1.Signal=ADCx_IN1
PA10.GPIO_Label=CS_IMU
PA10.Signal=GPIO_Output
PA11.Signal=USB_OTG_FS_DM
PA12.Signal=USB_OTG_FS_DP
PA13.Signal=SYS_JTMS-SWDIO
PA14.Signal=SYS_JTCK-SWCLK
PA2.GPIO_Label=RGBLEDControl
PA2.Signal=S_TIM2_CH3
PA3.GPIO_Label=AuxIgnite
PA3.Signal=GPIO_Output
PA5.Signal=SPI1_SCK
PA6.Signal=SPI1_MISO
PA7.Signal=SPI1_MOSI
PA8.GPIO_Label=GPS1ResetPin
PA8.Signal=GPIO_Output
PA9.Signal=USB_OTG_FS_VBUS
PB0.GPIO_Label=LoRaNssPin
PB0.Signal=GPIO_Output
PB1.GPIO_Label=LoRaDIO1
PB1.Signal=GPIO_Output
PB10.Signal=SPI2_SCK
PB11.GPIO_Label=CSAccelerometer
PB11.Signal=GPIO_Output
PB12.Signal=CAN2_RX
PB13.Signal=CAN2_TX
PB14.GPIO_Label=PyroIgnite
PB14.Signal=GPIO_Output
PB15.Signal=SPI2_MOSI
PB2.GPIO_Label=LoRaResetPin
PB2.Signal=GPIO_Output
PB4.Signal=SPI3_MISO
PB5.Signal=SPI3_MOSI
PB6.GPIO_Label=LoRaDIO0
PB6.Signal=GPIO_Output
PB7.GPIO_Label=LoRaDIO2
PB7.Signal=GPIO_Output
PC0.GPIO_Label=CSFlashmMemory
PC0.Signal=GPIO_Output
PC1.GPIO_Label=CS_SD_Card
PC1.Signal=GPIO_Output
PC10.Signal=SPI3_SCK
PC11.Signal=UART4_RX
PC12.Signal=UART5_TX
PC2.Signal=SPI2_MISO
PC3.Signal=ADCx_IN13
PC4.GPIO_Label=BuzzerControl
PC4.Signal=GPIO_Output
PC5.Signal=ADCx_IN15
PC6.GPIO_Label=DrougeIgnite
PC6.Signal=GPIO_Output
PC7.GPIO_Label=CSBarometer
PC7.Signal=GPIO_Output
PC9.GPIO_Label=GPS2ResetPin
PC9.Signal=GPIO_Output
PD2.Signal=UART5_RX
PH0-OSC_IN.Signal=RCC_OSC_IN
PH1-OSC_OUT.Signal=RCC_OSC_OUT

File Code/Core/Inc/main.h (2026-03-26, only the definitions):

#define CSFlashmMemory_Pin GPIO_PIN_0
#define CSFlashmMemory_GPIO_Port GPIOC
#define CS_SD_Card_Pin GPIO_PIN_1
#define CS_SD_Card_GPIO_Port GPIOC
#define RGBLEDControl_Pin GPIO_PIN_2
#define RGBLEDControl_GPIO_Port GPIOA
#define AuxIgnite_Pin GPIO_PIN_3
#define AuxIgnite_GPIO_Port GPIOA
#define BuzzerControl_Pin GPIO_PIN_4
#define BuzzerControl_GPIO_Port GPIOC
#define LoRaNssPin_Pin GPIO_PIN_0
#define LoRaNssPin_GPIO_Port GPIOB
#define LoRaDIO1_Pin GPIO_PIN_1
#define LoRaDIO1_GPIO_Port GPIOB
#define LoRaResetPin_Pin GPIO_PIN_2
#define LoRaResetPin_GPIO_Port GPIOB
#define CSAccelerometer_Pin GPIO_PIN_11
#define CSAccelerometer_GPIO_Port GPIOB
#define PyroIgnite_Pin GPIO_PIN_14
#define PyroIgnite_GPIO_Port GPIOB
#define DrougeIgnite_Pin GPIO_PIN_6
#define DrougeIgnite_GPIO_Port GPIOC
#define CSBarometer_Pin GPIO_PIN_7
#define CSBarometer_GPIO_Port GPIOC
#define GPS2ResetPin_Pin GPIO_PIN_9
#define GPS2ResetPin_GPIO_Port GPIOC
#define GPS1ResetPin_Pin GPIO_PIN_8
#define GPS1ResetPin_GPIO_Port GPIOA
#define CS_IMU_Pin GPIO_PIN_10
#define CS_IMU_GPIO_Port GPIOA
#define LoRaDIO0_Pin GPIO_PIN_6
#define LoRaDIO0_GPIO_Port GPIOB
#define LoRaDIO2_Pin GPIO_PIN_7
#define LoRaDIO2_GPIO_Port GPIOB

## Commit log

2026-03-01 Schematic changes
2026-03-03 output files got quote
    [Accelerometer.kicad_sch, Barometer.kicad_sch, Can_transceiver.kicad_sch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]
2026-03-04 finalized output files
    [Accelerometer.kicad_sch, FlashSd.kicad_sch, GPS2.kicad_sch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]
2026-03-14 ran dmf check fixed some things
    [flightcomputer2.kicad_pcb, power.kicad_sch]
2026-03-16 dfm sent for ordering
    [AuxPyro.kicad_sch, flightcomputer2.kicad_pcb]
2026-03-19 added DIO0 and DIO2 pins to read lora module outputs
    [LoRa.kicad_sch, MCU.kicad_sch, flightcomputer2.kicad_pcb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]
2026-03-19 updated .gitignore and fixed rf impedance things
    [flightcomputer2.kicad_pcb]

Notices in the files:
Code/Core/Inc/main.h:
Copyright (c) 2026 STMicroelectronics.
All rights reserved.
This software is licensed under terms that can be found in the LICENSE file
